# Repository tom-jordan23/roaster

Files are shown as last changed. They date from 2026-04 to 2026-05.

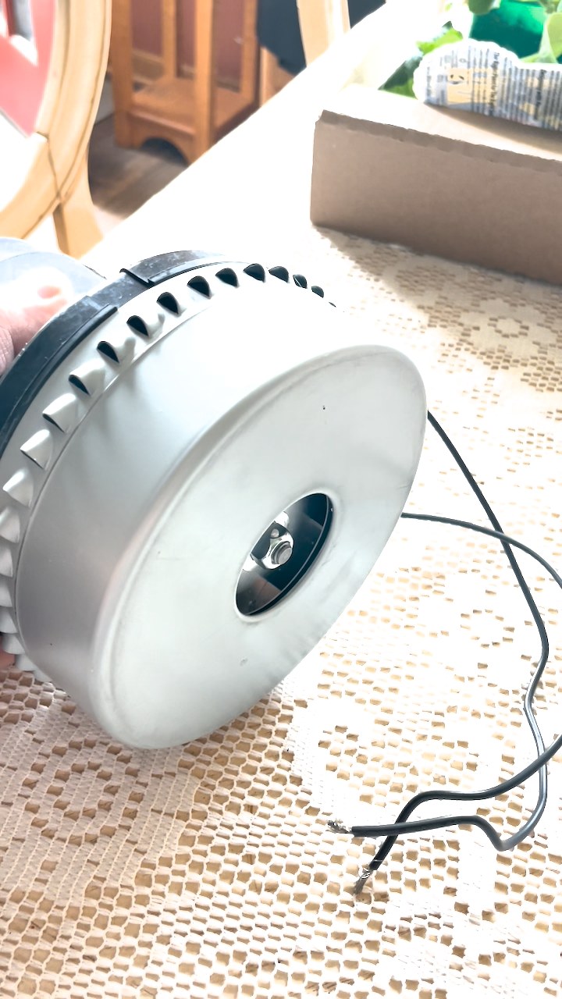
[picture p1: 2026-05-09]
build/photos/blower-motor/still_04_frame327.jpg

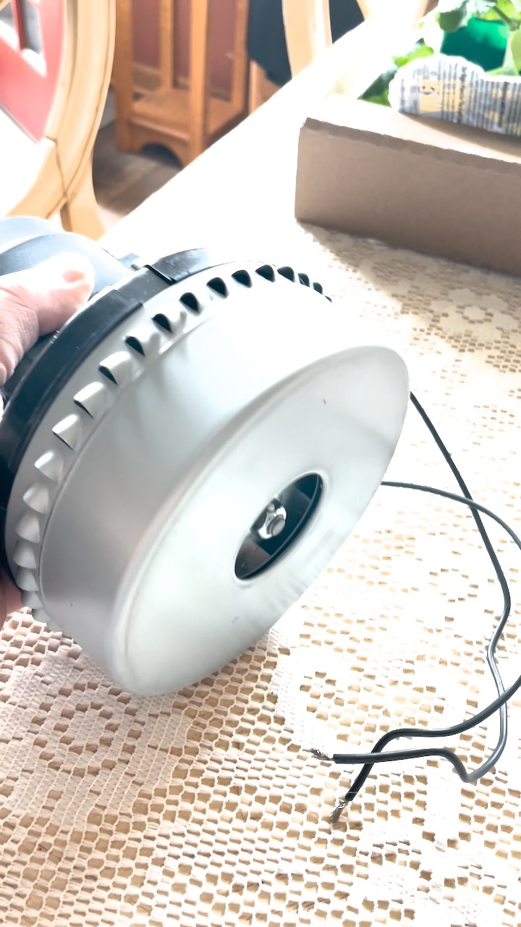
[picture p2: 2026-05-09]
build/photos/blower-motor/still_05_frame409.jpg

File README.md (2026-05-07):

# Fluid-Bed Coffee Roaster

A purpose-built small electric fluid-bed coffee roaster designed for 1/4 lb (113g) batches on 120V AC. Built as an engineering instrument and learning platform — manual operation first, closed-loop automation later.

## What This Is

A ground-up roaster design with:
- Stainless steel roast chamber with a round stovepipe plenum and side-entry heated air (DR-012)
- Distributor plate and internal baffles for uniform fluidization
- Three K-type thermocouples (process air, bean bed, exhaust)
- ESP32-based control with zero-cross SSR heater switching
- Serial command interface for manual control
- Artisan-compatible data logging
- Safety interlocks that are always authoritative

This is **not** a popcorn popper mod. It's a purpose-built fluid-bed architecture designed
to produce real roast data and evolve into a closed-loop system — built on the cheap
using thrift store finds, salvaged parts, and Amazon generics wherever possible.

## Project Status

**Phase 1 — Subsystem build (parts in hand).** Repository structure, system
architecture, power/airflow budgets, firmware scaffold, and full-design-review
disposition (DR-010) all complete. As of 2026-05-07, all major parts are in
hand: Warrior heat gun (HTR-001) torn down with element measured 1.5"×6";
salvaged bypass-cooled vacuum motor (BLW-001) measured 6"×6" cylindrical;
DR-011 control kit (TRIAC dimmer, ZMCT103C CT, line filter, ferrites);
8" stovepipe plenum body + caps (DR-012); 12"×24" steel sheet cut to
12"×18" deck with the remainder feeding the angle-iron frame extensions
(DR-013 tripod legs). Next: heater-can fabrication, plenum cure-burn,
frame extension build, electronics tray assembly, then TP-001 commissioning.

## Repository Structure

```
docs/
  system/          System block diagrams, architecture, design reviews
  mechanical/      Chamber, plenum, distributor plate, exhaust design
  electrical/      Schematics, power distribution, interlocks
  software/        Firmware architecture, Artisan integration, safety logic

firmware/          ESP32 PlatformIO project
  src/             Safety, sensors, heater, blower, control, logging, command
  test/            Unit tests (Unity framework)

bom/               Bill of materials and sourcing notes
test/plans/        Test plans TP-001 through TP-006
build/             Build instructions and progress photos
```

## Architecture Overview

### Air Path
```
Ambient → Blower → Heater Can → Plenum (side-entry) → Baffles → Distributor Plate → Chamber → Exhaust
```

### Control Stack
```
ESP32 ← 3x MAX31855 (TC1, TC2, TC3)
ESP32 → Zero-cross SSR (heater duty cycle)
ESP32 → Blower driver (speed control)
ESP32 → Serial/USB → Host PC (Artisan logging)
```

### Software Layers
1. **Safety layer** — always authoritative; over-temp shutdown, TC fault detection, airflow loss protection
2. **Manual control layer** — operator sets heater % and blower % via serial commands
3. **Automation layer** — initially stubbed; future PID on process air temp

## Firmware Commands

```
HEAT <0-100>    Set heater duty cycle %
BLOW <0-100>    Set blower speed %
STATUS          Request current state
RESET           Clear safety fault (if conditions allow)
STOP            Emergency stop — heater and blower off immediately
```

## Key Design Constraints

| Parameter | Value | Notes |
|---|---|---|
| Batch size | 113g green | 1/4 lb |
| Mains power | 120V / 15A | US residential |
| Heater budget | 1200-1500W | Salvaged from hair dryer or heat gun |
| Airflow (blower side) | 6-15 CFM | Range covers both chamber sizes |
| Chamber (primary) | 2.5" OD SS tube (~60mm ID) | Better thermal efficiency |
| Chamber (backup) | 3.0" OD SS tube (~73mm ID) | Easier fluidization |
| TC sample rate | 4 Hz polling, 2 Hz output | Artisan-compatible |
| Target BOM cost | $50-80 | Thrift-first sourcing strategy |

## Test Plan

Six test plans cover the full commissioning sequence:

| Plan | Name | Scope |
|---|---|---|
| TP-001 | Airflow | Distributor plate uniformity, fluidization verification |
| TP-002 | Thermal | Heater step response, steady-state characterization |
| TP-003 | Electrical Safety | Ground continuity, isolation, strain relief, smoke test |
| TP-004 | Firmware Unit | Automated tests + manual bench verification |
| TP-005 | Integration | Full system hot test with beans (not a roast) |
| TP-006 | First Roast | Conservative first roast through first crack |

Tests execute in order. Each depends on the prior test passing.

## Development Phases

| Phase | Goal | Gate |
|---|---|---|
| 0 - Foundation | Repo, architecture, budgets, firmware scaffold | DG-0: Agree on chamber size, heater watts, airflow rate |
| 1 - Subsystem Design | Mechanical, electrical, firmware module design | DG-1: Lock interfaces between subsystems |
| 2 - Detail | Fabrication drawings, final schematic, BOM, unit tests | DG-2: BOM ordered, firmware tests pass |
| 3 - Build & Commission | Assembly, test execution, first roast | DG-3: First roast data reviewed |

## Cost Strategy

This is a v1 learning platform built to be cheap and iterable. Major cost savings:

- **Heater element** — Harbor Freight Warrior heat gun, donor only ($10, DR-002)
- **Blower** — bypass-cooled vacuum motor salvaged from a junk shop vac
  ($0-10, DR-011); TRIAC dimmer + ZMCT103C current sensor for control
- **Chamber** — standard SS exhaust pipe from auto parts store ($8-12 each)
- **Plenum** — 8" round black stovepipe + pipe caps ($0 from scrap; ~$6 retail) (DR-012)
- **Electronics** — Amazon generic ESP32, MAX31855, SSR, TCs ($35-50 total)
- **5V supply** — old phone charger from junk drawer ($0)

We design the mechanical assembly around whatever parts we find, not the other way
around. See [`docs/system/design-reviews/DR-001-cost-strategy.md`](docs/system/design-reviews/DR-001-cost-strategy.md)
for full rationale.

## Design Documents

- [`claude.md`](claude.md) — full design rationale and decision history
- [`docs/system/design-log.md`](docs/system/design-log.md) — running design log
- [`docs/system/design-reviews/`](docs/system/design-reviews/) — formal decision records

## Building the Firmware

Requires [PlatformIO](https://platformio.org/).

```bash
cd firmware
pio run          # Compile
pio test         # Run unit tests
pio run -t upload  # Flash to ESP32
```

## License

This is a personal engineering project. No license specified yet.

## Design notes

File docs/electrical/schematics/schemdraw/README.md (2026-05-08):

# SchemDraw schematics

Source-of-truth schematics for the roaster, generated from Python via
[SchemDraw](https://schemdraw.readthedocs.io/). SVGs are checked in;
PNGs are regenerated alongside.

## Diagrams

| Source | Output | Domain |
|---|---|---|
| `01_mains_entry.py` | `out/01_mains_entry.svg` | Mains entry, DPST disconnect, fuse |
| `02_heater_circuit.py`  | `out/02_heater_circuit.svg` | Domain 1 - SSR, heater, thermal fuses, snubber, NPN buffer |
| `03_blower_circuit.py`  | `out/03_blower_circuit.svg` | Domain 2 - TRIAC dimmer, vacuum motor, CT, line filter, BOND-001 (DR-011) |
| `04_control_circuit.py` | `out/04_control_circuit.svg` | Domain 3 - ESP32 + 3x MAX31855 SPI bus + cross-domain stubs |
| `05_grounding.py` | `out/05_grounding.svg` | Star grounding plan (chassis vs. signal) |
| `06_panel_mains_entry.py` | `out/06_panel_mains_entry.svg` | Panel-wiring zone 1/4: mains entry (cord, switch, fuse, buses) |
| `07_panel_heater_bay.py`  | `out/07_panel_heater_bay.svg` | Panel-wiring zone 2/4: heater bay (thermal fuses, SSR, drive buffer) |
| `08_panel_blower_bay.py`  | `out/08_panel_blower_bay.svg` | Panel-wiring zone 3/4: blower bay (filter, CT, dimmer, motor) |
| `09_panel_control_bay.py` | `out/09_panel_control_bay.svg` | Panel-wiring zone 4/4: control bay (PSU, ESP32, MAX31855 ×3) |

## Regenerate

```bash
./docs/electrical/schematics/schemdraw/render_all.sh
```

The script bootstraps a venv at `<repo>/.venv-diagrams/` on first run
(requires `python3` and `python3-venv`). Subsequent runs reuse it.

## Conventions

- **Wire colors**: red = mains hot (L), grey = mains neutral (N),
  green = protective earth (PE), orange = +5 V logic supply,
  purple = 3.3 V logic, black = signal.
- **Boxes**: drawn with the `box(d, x0, y0, x1, y1)` helper in `common.py`.
  Always pass absolute drawing coordinates - the helper handles the
  element-relative-corner and element-direction footguns.
- **Em-dashes break the SVG backend**. Use `-` in labels.

## Editing

Each script is small and self-contained. Open one of the existing files to
see the coordinate-grid pattern: declare a few `Y_*` and `X_*` constants,
then place every element with `.at((x, y))` in absolute coordinates. Avoid
relying on cursor position after the first element - schemdraw inherits
direction from the previous element, which has bitten us already.

After editing a `.py`, run `render_all.sh` (or `python <name>.py` for one).

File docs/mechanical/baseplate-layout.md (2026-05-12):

# Baseplate Layout — Mechanical and Electronics Placement

## Purpose

Top-down layout of the v1 roaster baseplate: where each major component sits,
where the electronics tray goes, and how mains and signal wiring are routed.

This doc is **manual-first text + diagrams**. The OpenSCAD model
(`roaster-assembly.scad`) does not yet reflect this layout; SCAD changes are
gated on the vacuum motor being in hand (DR-011, design-log
2026-04-29). Once the motor is measured, both the SCAD model and this doc
should be updated together.

References: `docs/system/architecture.md` §3, `docs/electrical/schematics/power-schematic.md`,
`docs/system/design-log.md` (DR-005, DR-007, DR-008, DR-009, DR-011), `bom/bom-master.csv`.

---

## 1. Constraint Audit Against the SCAD Model

Numbers below reflect the as-built **12" × 18" steel deck** cut from the
24" BASE-001 stock, mounted on a 1"-class angle-iron frame with rear and
front extensions for the motor and electronics tray respectively (the
remaining 6" of stock is reserved for the frame extension stock and
gussets). The motor (BLW-001) and heater element (HTR-001) are now in hand
and measured; previous placeholder geometries are replaced with measured
values.

| Parameter | Value | Notes |
|---|---|---|
| Deck | 305 × 457 mm (12" × 18") | Steel sheet cut from the BASE-001 24" stock; the air train sits on this, and motor/electronics live on frame extensions outboard of it |
| Frame | 1"-class angle iron: perimeter on the deck + a rear extension for the motor + a front extension for the electronics tray | M1 stiffening + structural carry for off-deck loads. Final extension lengths set by §3 below |
| Legs | 3× threaded rod tripod, extending above and below baseplate | DR-013 tip-resistance strategy: rods continue up past the baseplate to a clamp around the cone reducer or upper chamber. Tripod gives lateral stability without the complications of running the chamber tube down into the plenum (TC-002 mount, chamber swap). Below the baseplate, same rods are the feet — adjustable for leveling |
| Plenum footprint | 203 mm dia × 152 mm tall (8" × 6") | DR-012 — round black stovepipe, both ends capped; vertical axis |
| `heater_can_length` | 178 mm (7") | **Measured 2026-05-07** — 1.5" × 6" Warrior element pack + ~0.5" each end for inlet/outlet fittings; 2.5" OD SS exhaust pipe (HTR-CAN-001) |
| `blower_dia` × `blower_height` | 152 × 152 mm (6" × 6"), vertical-axis cylinder | **Measured 2026-05-07** — aftermarket Lamb 116336-01-pattern bypass-cooled vacuum motor (BLW-001) in hand; outlet exits radially at heater-can centerline elevation |

### Air-train pack length and frame extensions

Working from the design pack length along the long (Y) axis, with the
motor and plenum on extensions outboard of the deck:

    rear extension ─ deck (457 mm) ─ front extension
    ┌──── motor 152 ────┬─── heater can 178 ──┬── plenum 203 ──┐ ── electronics tray ──┐
    │ entirely on rear  │     on deck         │   on deck      │  on front extension   │
    └ extension (~152)  │ (Y=25 to Y=203)     │ (Y=228 to 431) │  (Y=470 to ~595)      ┘

- **Motor** (Zone A, rear): mounted entirely on the rear angle-iron extension,
  body centered ~75 mm rear of the deck rear edge. Outlet faces forward and
  joins the heater can at the deck rear edge via a short flex elbow + hose
  clamp. **Rear extension length: ~152 mm (6").**
- **Heater can** (Zone B): on the deck, axis along Y, occupies Y = 25 mm to
  Y = 203 mm (25 mm rear margin for the motor-outlet joint).
- **Plenum** (Zone C): on the deck, vertical axis, with the side-entry stub
  (PLEN-005) crossing Y = 203 mm to Y = 228 mm. Plenum body (8" dia) occupies
  Y = 228 mm to Y = 431 mm — sits comfortably inside the 457 mm deck with
  ~26 mm front-edge margin to the heat-barrier line.
- **Electronics tray** (Zone D): on a front angle-iron extension, ~125 mm
  (5") deep, behind the heat barrier shield. Mounting it on an extension
  (rather than cramming it into the 26 mm of deck remaining) is the cleanest
  way to preserve the original 5"-deep enclosure while keeping the deck
  reserved for the air train. **Front extension length: ~125 mm (5").**

Total assembly footprint along Y: 152 (rear ext) + 457 (deck) + 125 (front
ext) = **734 mm (28.9")**. This is comparable in length to the originally
planned 24" baseplate but with the heat-bearing portion (deck + air train)
restricted to the 18" steel sheet — the angle-iron extensions carry only
cool-zone loads (motor body which runs at 60–80°C ambient, electronics
tray which targets <40°C internal).

### Why this layout

1. **Motor off the deck.** The motor is the heaviest single part and is the
   primary tipping moment contributor. Placing it on a rear angle-iron
   extension, with the rear pair of tripod legs straddling it, anchors the
   motor weight directly to the legs rather than cantilevering it over the
   deck edge.
2. **Plenum on deck, near front-of-deck.** The plenum carries the chamber
   stack — the tallest, most tip-prone subassembly — so it stays inboard of
   the deck where the front pair of tripod legs and the chamber-band clamp
   (DR-013) provide rigid support.
3. **Heat-barrier sheet between the plenum and the electronics tray.** The
   barrier bolts to the deck front edge with grommeted pass-throughs for the
   SSR drive pair and the TC leads (see §4.1). Putting the electronics tray
   on a front extension preserves the ~1" air gap and keeps the barrier free
   of cable congestion.
4. **Steel deck reserved for the hot zones (B + C).** The deck takes the
   thermal load (heater can + plenum, both >150°C surface temps even
   insulated). Cool-zone components (motor envelope at 60–80°C, electronics
   at <40°C) sit on angle-iron extensions outboard of the deck where the
   thermal gradient is small.

---

## 2. Layout Zones

The full assembly footprint is divided into five functional zones. Zones A–D
lie along the long (Y) axis on the baseplate plane; Zone E rises vertically
above the front extension. Zones B and C live on the 12" × 18" steel deck;
Zones A and D live on angle-iron frame extensions outboard of the deck;
Zone E is a vertical riser carrying the Pi 5 host + 7" display (DR-017):

```
       +Y (operator / front edge)
                ┌───────────────────────────────┐
                │   ZONE E — HOST UI (riser)    │ ← vertical, tilted back ~20°
                │   Pi 5 + 5×7" HDMI touch      │   facing operator
                │   mounted to a stalk          │
                └──────────┬────────────────────┘
                           │ riser attaches to front edge of
                           │ front extension; USB-A cable
                           ▼ drops back into Zone D
       ┌─ FRONT EXTENSION (~5" × 12" angle-iron tray support) ─┐
       │  ZONE D — ELECTRONICS TRAY        ~5" × 12"           │
       │                                                       │
       ╠═══════════════════ heat barrier ══════════════════════╣ ← deck front edge
       ║  ZONE C — PLENUM + CHIMNEY        ~8" dia, on deck    ║
       ║          (8" round stovepipe per DR-012;              ║
       ║           tripod legs straddle it — DR-013)           ║
       ║                                                       ║
       ║  ZONE B — HEATER CAN + SSR        ~7" × 4", on deck   ║   air-train axis
       ║                                                       ║
       ╠═══════════════════════════════════════════════════════╣ ← deck rear edge
       │  ZONE A — BLOWER + AC CONTROL     6" dia motor body   │
       │          (vertical axis) + TRIAC dimmer + line filter │
       │  [MAINS ENTRY: cord grip → DPST → fuse]               │
       └─ REAR EXTENSION (~6" × 12" angle-iron motor cradle) ──┘
       -Y (rear edge)
```

| Zone | Location | Function | Thermal class | EMI class |
|---|---|---|---|---|
| A | Rear extension (off deck) | Blower, TRIAC dimmer, line filter, mains entry, CT, ferrites | Warm (motor body 60–80°C) | **Hot** (TRIAC + brushed motor) |
| B | Deck (Y = 25–203 mm) | Heater can, SSR + heatsink, snubber, airstream thermal fuse, TC1 | **Hot** (can surface >200°C even insulated) | Quiet |
| C | Deck (Y = 228–431 mm) | Plenum, chimney, distributor plate, baffle, TC2, exhaust + chaff collector + TC3 | Hot (plenum 150–200°C, chimney 100–200°C) | Quiet |
| D | Front extension (off deck) | ESP32, MAX31855 ×3, 5V PSU, SSR drive buffer, CT bias network, USB out | **Cool** (target <40°C) | **Quiet** (target) |
| E | Riser above front extension | Pi 5 host + 5×7" HDMI touch display, USB tether down to Zone D | **Cool** (target <40°C, Pi 5 rated 0–50°C ambient) | Quiet |

The heat barrier is a vertical sheet-metal shield bolted to the deck front
edge between Zones C and D, with grommeted pass-throughs for the SSR DC
drive pair and the TC probe leads. The shield is bonded to chassis ground.
Putting Zone D on the front extension (rather than on the deck itself)
preserves the original ~1" air gap behind the barrier without crowding the
plenum.

---

## 3. Air-Train Component Placement (Zones A–C)

### 3.1 Blower (Zone A — rear extension)

| Aspect | Spec |
|---|---|
| Component | BLW-001 (aftermarket Lamb 116336-01-pattern bypass-cooled vacuum motor) — **in hand 2026-05-07** |
| Body geometry | Cylindrical, **6" dia × 6" tall** (152 × 152 mm); shaft vertical |
| Mounting position | Centered on the rear angle-iron extension, ~75 mm rear of the deck rear edge; body centerline aligned with the air-train Y axis |
| Mounting hardware | Bolted to a sheet-metal saddle or strap, sitting on the angle-iron extension. Tripod rear legs straddle the motor on either side |
| Outlet routing | BLW-HOUS-001 fan shell on top of motor; outlet is **axial** (vertical, parallel to motor shaft, off-center on the dome face). BLW-ELBOW-001 1.5in silicone 90° elbow turns the discharge horizontal-forward, then BLW-COUP-001 1.5→2.5in silicone reducer carries it across the deck rear edge to the heater can inlet at heater-can centerline elevation. (Axial-outlet shape was confirmed via product-photo inspection 2026-05-09 — DR-015) |
| Cooling exhaust | Directed away from operator and Zone D (down through a clearance gap in the rear extension, or sideways out −X) |
| Vibration isolation | Rubber feet or grommeted bolts at the saddle/extension interface; the universal motor will vibrate |
| Frame bonding | BOND-001 — ring terminal under a frame screw to the chassis-ground bus |

### 3.2 AC blower control (Zone A, adjacent to motor)

| Aspect | Spec |
|---|---|
| BLW-CTRL-001 | TRIAC dimmer module on standoffs ~50 mm from motor body |
| FILT-001 | AC line filter, inline on motor L+N leads, between fuse bus and dimmer |
| CT-001 | Split-core CT clamped on the motor's L lead **between the dimmer and the motor** so it sees the gated AC waveform |
| FERR-001 | Snap-on ferrite on motor leads between the dimmer output and the motor body |

The TRIAC dimmer must stay near the motor — short motor leads bound the
EMI source. Only three logic-level wires (PWM, ZC, GND) leave Zone A
toward Zone D.

### 3.3 Heater can (Zone B)

| Aspect | Spec |
|---|---|
| Component | HTR-CAN-001 (built per M5: 2.5" SS exhaust pipe, element on mica former, ceramic fiber wrap exterior) |
| Element | HTR-001 Warrior 1500W nichrome on mica former, **measured 2026-05-07: 1.5" wide × 6" long element pack** |
| Can length | **178 mm (7")** — 6" element + ~0.5" each end for inlet/outlet transition fittings |
| Can OD | 2.5" (~64 mm) SS exhaust pipe |
| Mounting | Cradled in two formed sheet-metal saddles bolted to deck; saddles lined with high-temp gasket to avoid metal-to-metal heat conduction |
| Joints | Hose clamp at blower outlet (preserves DR-005 bypass-cooling option); hose clamp at plenum side-entry stub tube (PLEN-005, M2) |
| THFUSE-001 | Mounted on can body exterior, in series with heater (independent of MCU) |
| THFUSE-002 | Mounted in the heated airstream, downstream of the element, immediately upstream of the plenum side-entry (E6) |
| TC1 | K-type probe via TC-FIT-001 compression fitting, in the heated airstream just upstream of plenum side-entry |

### 3.4 SSR (Zone B, baseplate-side of the heat barrier)

| Aspect | Spec |
|---|---|
| Component | SSR-001 + finned heatsink |
| Position | On the +Y side of the heater can, between can and the heat barrier |
| Heatsink orientation | Fins vertical for natural convection (~15–20 W dissipation at 12.5 A continuous) |
| Snubber | R-SNB + C-SNB across SSR output terminals (E10) |
| DC drive | Two short pigtails (SSR+, SSR-) cross the heat barrier through a grommet to Q2 buffer in Zone D |

The SSR is *not* in the electronics tray. Keeping it on the air-train side
shortens the high-current SSR-to-element wiring and concentrates the
Zone D enclosure on cool-running parts only.

### 3.5 Plenum and chimney (Zone C)

The plenum (DR-012: 8" dia × 6" tall black-stovepipe section, both ends
pipe-capped) sits centered on the +Y portion of the baseplate, vertical
axis. The chimney (distributor plate → roast chamber → cone reducer →
chaff expansion chamber → mesh screen) rises from the top cap, which is
drilled to the chamber OD and carries the clamping ring on its underside.
This zone is driven by DR-008, DR-009, DR-012 and is unchanged by DR-011.

Round footprint vs. the prior rectangular steam-pan plan: the 8" diameter
exceeds the 6"×7" rectangular Zone-C estimate by ~1" on the X axis but
remains comfortably inside the 12" baseplate width once the +X wire lanes
(§5) are accounted for.

| TC | Mount point |
|----|---|
| TC-002 | Lower chamber side wall via TC-FIT-001 (bean-bed temperature) |
| TC-003 | Exhaust stream above the chamber, via TC-FIT-001 (M9) |

### 3.6 Mains entry (rear edge of Zone A)

Cord enters the rear edge through a strain relief (STRAIN-001) and runs
**along the rear edge** to:

    cord → STRAIN-001 → SW-001 (DPST) → FUSE-001 (15A) → L bus + N bus + chassis-ground bus

SW-001 is mounted through the rear face of an enclosed Zone-A panel so it
is reachable but not bumpable. (See §6 for the case where SW-001 moves to
the front face instead.)

---

## 4. Electronics Tray (Zone D)

A small enclosed or fenced area at the operator end of the baseplate,
~5" deep × 12" wide, separated from Zone C by the heat barrier.

### 4.1 Enclosure

A vented project box (~6" × 4" × 2", or fabricated from sheet metal) bolted
to the baseplate. Vents on the +Y face only (away from the heat barrier).
Target internal temperature <40°C during a roast — verify in TP-001 with a
TC taped to the inside of the enclosure.

### 4.2 Internal placement

From rear (heat-barrier side) to front (operator side):

| Row | Component | Notes |
|-----|---|---|
| Rear  | Q2 + R3 (SSR drive buffer, E7) | On the same protoboard as the ESP32; pigtails through the heat-barrier grommet to SSR DC input |
| Rear  | CT bias network (burden R + offset divider) | Short shielded run from CT-001 in Zone A; bias network references signal ground |
| Mid | ESP-001 (ESP32-DevKitC) | On standoffs; orientation chosen so USB connector faces the front face of the enclosure |
| Mid | TC-AMP-001 ×3 (MAX31855 boards) | Same protoboard as ESP; CS lines short (<50 mm) |
| Front | PSU-001 (5V USB charger) | Mains side of the enclosure; output USB-A or pigtailed to ESP32 VIN |
| Front face | USB-B / USB-C pass-through | Strain-relieved, to host PC running Artisan |
| Front face | Optional indicator LEDs or small status display | Future — not v1 |

### 4.3 Components that do **not** live in the electronics tray

| Component | Lives in | Why |
|---|---|-----|
| BLW-CTRL-001 (TRIAC dimmer) | Zone A | Keep motor leads short; bound the EMI source |
| CT-001 | Zone A | Must be physically clamped on a motor lead |
| FILT-001 | Zone A | Inline on motor mains leads |
| FERR-001 (motor-side) | Zone A | On motor leads |
| FERR-001 (TC-side) | One on each TC SPI cable, both at the amp end and the probe end | Distributed; not localized |
| SSR-001 + heatsink | Zone B | Air-train side of heat barrier; short high-current wiring to element |
| THFUSE-001 / THFUSE-002 | Zone B | On the can body and in the airstream |
| FUSE-001 + SW-001 | Rear edge of Zone A (or front face — see §6) | Mains protection lives with mains entry |

---

## 5. Host UI Mount (Zone E)

Zone E carries the **Pi 5 + 5×7" HDMI touch display** (DR-017) as an
integrated unit mounted to the front edge of the front extension, rising
vertically above Zone D. The display faces the operator; the Pi mounts
behind the display so the whole assembly is a single tilt-back stalk.

### 5.1 Geometry

| Aspect | Value | Notes |
|---|---|---|
| Display active area | ~127 × 178 mm (5" × 7") | On hand — generic HDMI panel |
| Display + bezel (estimated) | ~152 × 203 mm (6" × 8") | Verify on the actual display before final bracket fab (G3) |
| Pi 5 PCB | 85 × 56 mm | Mounted directly to the back of the display via M2.5 standoffs |
| Riser base footprint | ~75 × 100 mm | Bolts to the front face of the front extension; small footprint so it doesn't crowd Zone D |
| Display orientation | Landscape, tilted back ~15–20° | Comfortable operator viewing angle while standing |
| Pi 5 cooling clearance | ≥20 mm above the active cooler fan intake | Don't enclose the back; let it breathe |

### 5.2 Mount detail

The riser is fabricated from BASE-001 angle-iron offcut or 1"-class steel
flatbar. Two M5 bolts through the front extension face into a vertical
stalk; stalk top carries a flat plate to which the display is fastened
through its existing VESA-style or perimeter mount holes. Pi 5 mounts to
standoffs on the back of the display plate.

### 5.3 Cable routing

Two cables run from Zone E down into Zone D:

- **micro-HDMI → HDMI** (`UI-005`): video from Pi 5 to display. Both cable
  ends stay in Zone E; the cable does not cross zones.
- **USB-A → display USB** (combined power + touch): runs along the back of
  the riser, ferrite at the Pi end, terminates at the display's USB port.

A third cable runs from Pi 5 USB-A out to the ESP32 in Zone D:

- **USB-A → ESP32** (`UI-006`): drops vertically from the Pi 5 down the
  back of the riser, ferrite at the Pi end, follows the +X signal lane
  into Zone D's front face USB pass-through.

All three cables travel along the back of the riser, out of operator sight.

### 5.4 Thermal considerations

Pi 5 is rated 0–50°C ambient. The riser places the Pi ~250 mm forward of
Zone C (plenum, 150–200°C surface). The existing Zone C/D heat barrier
(see §2) plus the ~150 mm vertical separation from the deck plane keep Pi
ambient well under spec under normal operation. Verify in TP-001 with a TC
taped to the Pi 5 active-cooler intake during a soak run.

Display backlight self-heating is the secondary concern — most 5×7" panels
run cool, but enclosed mounts can trap heat behind the panel. Leave the
back of the display open (Pi 5 mounted on standoffs, not flush) for
convective dissipation.

### 5.5 EMI

The Pi 5 USB rail is the EMI-sensitive path here (the ESP32 USB serial
link rides it). Ferrites at the Pi end of the USB-to-ESP32 cable
(`FERR-001` inventory) mitigate TRIAC/motor noise re-injected via the USB
cable. WiFi (for the WebLCDs iPad bridge) lives on the Pi's internal radio
— no antenna routing needed.

### 5.6 Power

Pi 5 USB-C PSU (`UI-002`, 27 W) connects to the Pi at the riser. The
display draws its power from one of Pi 5's USB-A ports (G2 — requires
`usb_max_current_enable=1` on the Pi). No separate display PSU. The Pi's
USB-C input cord exits the back of the riser and joins the +X signal lane
back to the rear edge where it leaves the chassis alongside the mains
cord (different cord, different strain relief).

### 5.7 Open items

| Item | What unblocks it |
|---|---|
| Exact display dimensions + mount-hole pattern | Pull the display, measure perimeter, identify any factory mount holes |
| Riser stalk height | Set so display centerline is at operator eye level when standing in front of the assembly (~1100–1300 mm above floor); needs the leg height from DR-013 to pin down |
| Cardboard mockup of Zone E + Zone D fit | Cut a 152 × 203 mm cardboard rectangle, position on the riser stub, verify it doesn't shadow the air-train work area or block the chamber view |

---

## 6. Wire Routing — Three Lanes

All wiring runs along the **+X edge** of the baseplate (the long edge
opposite the air train), in three physically separated channels. This
keeps wiring entirely outside Zones B and C's hot/EMI footprint.

| Lane | Position | Carries | Wire spec |
|---|---|---|---|
| **Mains** | Elevated raceway ~25 mm above baseplate, on the +X edge | L/N from cord through fuse and switch; L+N to SSR; L+N through FILT-001 and TRIAC to motor | 14 AWG THHN, in metal conduit or solid raceway |
| **Heater control** | Short crossing of the heat barrier through a grommet, **perpendicular** to the mains lane | SSR DC input pair (5V, GND from Q2 buffer) | 22 AWG twisted pair |
| **Signal** | Plastic raceway ~25 mm **below** the mains lane, on the **outside** of the +X edge | TC SPI runs to TC1/TC2/TC3 amps (already inside the tray, so most of this lane is the TC probe leads going *up* the chimney); CT-001 secondary leads from Zone A to the bias network in Zone D; ESP32-to-dimmer logic (PWM, ZC, GND) | 22 AWG silicone hookup; shielded cable for SPI runs and CT secondary; twisted pair for ZC and PWM |

### Routing rules

- **No shared conduit** between mains and signal lanes — separate raceways.
- **Right-angle crossings only** when the signal lane must cross the
  mains lane; minimize crossing length.
- **Ferrite at every crossing** (FERR-001 inventory).
- **Ferrite at both ends of every TC SPI cable** (E13 + DR-011 EMI plan).
- **Shield grounded at one end only** (the ESP32 / amp end) to prevent
  ground loops.
- **CT-001 secondary** is a twisted shielded pair from Zone A to the bias
  network in Zone D; the secondary is referenced to signal ground via the
  bias network — **not** to chassis ground.

### Grounding bus

A single chassis-ground bus (brass strip or grounding stud) on the
**rear-right corner** of the baseplate, fed from the green wire of the
mains cord. Star topology — no daisy-chains. Bond points, each on its own
dedicated wire to the bus:

- Plenum pan ground lug
- Heater-can ground lug
- SSR heatsink (if metal)
- Blower motor frame (BOND-001)
- Heat-barrier shield
- Baseplate (if metal)

Signal ground (5V PSU GND, ESP32 GND, MAX31855 GNDs, TRIAC dimmer logic
GND) returns to a star point at the 5V PSU output, **not** to chassis
ground. Reaffirms the existing rule from `power-schematic.md`.

---

## 7. Open Issues / Pending Parts

| Item | Why it's pending | What unblocks it |
|---|---|---|
| ~~Motor footprint and outlet geometry~~ | ~~DR-011: salvaged motor not yet on bench~~ | **In hand 2026-05-07** — 152 × 152 mm vertical-axis cylinder; outlet geometry confirmed sufficient for vertical-axis mount |
| ~~Heater-can length~~ | ~~HTR-001 not yet torn down~~ | **Measured 2026-05-07** — element 1.5" × 6"; HTR-CAN-001 length set to 178 mm (7") |
| ~~Plenum body sourcing~~ | ~~PLEN-001 thrift hunt pending~~ | **Resolved by DR-012** — black stovepipe scrap on hand; 8" × 6" target |
| ~~Baseplate sheet sourcing~~ | ~~BASE-001 not yet sourced~~ | **Sourced 2026-05-02; cut to 12" × 18" deck 2026-05-07** — angle iron from same stock for perimeter + rear (motor) and front (electronics) extensions |
| Frame extension fabrication | Rear extension (~6") and front extension (~5") not yet built | Cut and weld/bolt angle iron onto the deck perimeter; install motor saddle on rear extension; install electronics-tray cradle on front extension |
| Electronics enclosure dimensions | SSR heatsink size and PSU brick size both still nominal | Parts received (most are now in hand 2026-05-07; lay them out and finalize the project box dims) |
| SW-001 placement (rear vs front face) | Reachability vs. cable-length tradeoff | Decide once Zone-A panel orientation is fixed by motor geometry |
| Verification of <40°C inside Zone D | Depends on heat-barrier effectiveness | TP-001 — instrument enclosure interior with a TC during a soak run |
| ~~L-bracket / ballast plan for stability (M1)~~ | ~~Depends on final mass distribution~~ | **Resolved by DR-013** — threaded-rod tripod legs continuing up to a chamber clamp provide lateral tip resistance. Final rod length and clamp height set once chamber stack is assembled |
| Tripod foot positions | Depends on final extension geometry | Front pair straddle the plenum on the deck; rear pair straddle the motor on the rear extension. Final coordinates set once the angle iron is cut |
| Zone E riser geometry (DR-017 G3) | Display perimeter dimensions and mount-hole pattern not yet measured; riser stalk height depends on final leg length | Pull the on-hand 5×7" display, measure perimeter, identify any factory mount holes; cardboard-mock the assembly against the air-train view before drilling |

---

## 8. Cross-References

- Architecture: `docs/system/architecture.md` §3, §3.1, §8
- Schematics: `docs/electrical/schematics/power-schematic.md`
- BOM line items used in this doc: HTR-001, HTR-CAN-001, BLW-001,
  BLW-CTRL-001, CT-001, FILT-001, FERR-001, BOND-001, SSR-001, ESP-001,
  TC-AMP-001 (×3), TC-001/002/003, TC-FIT-001, PSU-001, SW-001, SW-002,
  LED-001, LED-002, FUSE-001, STRAIN-001, THFUSE-001, THFUSE-002,
  R-SNB-001, C-SNB-001, Q2-001, R3-001, PLEN-001, PLEN-005, BASE-001,
  UI-001 through UI-007
- Design decisions referenced: DR-002, DR-005, DR-007, DR-008, DR-009,
  DR-011, DR-016, DR-017; M1, M2, M5, M9; E6, E7, E10, E13; T1
- SCAD model (to be updated when motor is in hand): `docs/mechanical/drawings/roaster-assembly.scad`

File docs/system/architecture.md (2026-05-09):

# System Architecture and Power/Airflow Budget

## Purpose

This document captures the foundational engineering calculations that constrain
component selection across all disciplines. The three critical numbers —
**heater wattage**, **airflow rate**, and **blower static pressure** — must be
established before detailed subsystem design can proceed.

These are first-pass estimates for a 1/4 lb (113g) green coffee batch on 120V AC.

---

## 1. Heater Power Budget

### Approach

Estimate the power needed to heat a stream of air from ambient to roast-process
temperature at the required airflow rate.

### Knowns and Assumptions

| Parameter | Value | Source |
|---|---|---|
| Batch size | 113 g green coffee | Design decision |
| Target process air temp (TC1) | 200–250°C | Typical fluid-bed roast range |
| Ambient air temp | 20°C | Assumed room temp |
| Required ΔT | 180–230°C | Process air minus ambient |
| Available mains | 120V / 15A circuit | US residential standard |
| Max continuous draw | ~1440W at 12A | Leave headroom on 15A breaker |

### Thermal Calculation

Power to heat air:

    P = ṁ × Cp × ΔT

Where:
- ṁ = mass flow rate of air (kg/s)
- Cp = specific heat of air ≈ 1005 J/(kg·°C)
- ΔT = temperature rise (°C)

For a target airflow of ~35 CFM (see Section 2 below):

    35 CFM ≈ 0.0165 m³/s
    ρ_air at 20°C ≈ 1.2 kg/m³
    ṁ ≈ 0.0165 × 1.2 = 0.0198 kg/s

Power for ΔT = 200°C:

    P = 0.0198 × 1005 × 200 ≈ 3980 W

Power for ΔT = 180°C:

    P = 0.0198 × 1005 × 180 ≈ 3580 W

### Problem: 120V Constraint

At 120V / 15A, we have at most ~1500W available (with blower and controls overhead,
realistically ~1200-1400W for the heater).

This means we **cannot** heat 35 CFM of air to 250°C. We must either:

1. **Reduce airflow** — use the minimum airflow needed for fluidization
2. **Accept lower process air temps** — rely on longer roast times
3. **Both** — minimize airflow, accept moderate temps, and tune from there

### Revised Estimate: Minimum Viable Airflow

For 113g of green coffee in a ~3" diameter chamber, fluidization likely requires
significantly less than 35 CFM. Estimates from similar small roasters suggest
**15-25 CFM** may be sufficient (see Section 2).

At 20 CFM:

    20 CFM ≈ 0.00944 m³/s
    ṁ ≈ 0.00944 × 1.2 = 0.01133 kg/s

Power for ΔT = 200°C:

    P = 0.01133 × 1005 × 200 ≈ 2277 W

Still too high. At ΔT = 120°C (process air at 140°C — low but possibly workable
with extended roast and recirculated heat from the bean mass):

    P = 0.01133 × 1005 × 120 ≈ 1365 W  ✓ Fits 120V budget

### Working Heater Specification

| Parameter | Target | Notes |
|---|---|---|
| Heater power | **1200–1400W** | Constrained by 120V/15A |
| Heater element type | Nichrome on mica former (Warrior heat gun) | Salvaged from HF SKU 56434 |
| Heater voltage | 120V AC | Switched by zero-cross SSR |
| Expected process air ΔT | 100–150°C at working airflow | Actual achievable temp depends on airflow, losses |

### Implications

- The 120V constraint makes this a **thermally modest** system
- Roast times will likely be **longer than commercial fluid-bed roasters** (8-15 min vs 5-8 min)
- Insulating the heater can and plenum will matter for efficiency
- The distributor plate and chamber should minimize heat loss
- **This is acceptable for v1** — the goal is to characterize and learn, not to match commercial speed

---

## 2. Airflow Budget

### Fluidization Requirements

For green coffee beans (~7mm equivalent diameter, ~1.1-1.3 g/cm³ density):

**Minimum fluidization velocity (Umf)** for coffee beans is approximately
**0.8–1.2 m/s** based on published fluidization studies and small-roaster
experience.

**T5 — Operating margin:** The original 1.5× Umf target is thin. Target
**1.8–2.5× Umf** for stable fluidization with margin for bed weight changes.
All velocity calculations must use hot-air density at process temperature
(~0.7–0.8 kg/m³ at 150–200°C), not ambient density. Previous calculations
applied this correction inconsistently.

### Chamber Cross-Section — Two Candidates

We are sourcing **two standard stainless steel tube sizes** and will test both.
This avoids committing to a chamber diameter before we have fluidization data.

**2.5" OD tubing** (ID ~2.37" / 60mm) — the thermal-efficiency candidate:

    Area = π × (0.030)² = 0.00283 m²

    Volumetric flow at 2.0× Umf = 2.0 m/s (T5: revised from 1.5×):
    Q = 2.0 × 0.00283 = 0.00566 m³/s ≈ 12.0 CFM

    Bed depth for 113g (bulk density ~0.65 g/cm³):
    V_bed = 113 / 0.65 = 174 cm³
    Depth = 174 / 28.3 ≈ 6.1 cm

    T3: L/D ratio = 6.1 / 6.0 ≈ 1.0 — WARNING: Geldart D particles (coffee beans)
    slug at L/D > 0.5-0.8. The 2.5" chamber has a significant slugging risk.

    Power for ΔT = 200°C at 12 CFM:
    ṁ = 0.00566 × 1.2 = 0.00679 kg/s
    P = 0.00679 × 1005 × 200 ≈ 1364 W  ✓ Within 120V budget

**3.0" OD tubing** (ID ~2.87" / 73mm) — the safe-fluidization candidate:

    Area = π × (0.0365)² = 0.00419 m²

    Volumetric flow at 2.0× Umf = 2.0 m/s (T5: revised from 1.5×):
    Q = 2.0 × 0.00419 = 0.00838 m³/s ≈ 17.7 CFM

    Bed depth for 113g:
    Depth = 174 / 41.9 ≈ 4.2 cm

    T3: L/D ratio = 4.2 / 7.3 ≈ 0.57 — within acceptable range for fluidization.

    Power for ΔT = 200°C at 17.7 CFM:
    ṁ = 0.00838 × 1.2 = 0.01006 kg/s
    P = 0.01006 × 1005 × 200 ≈ 2022 W  ⚠ Exceeds 120V budget

    T4: After 100-230W parasitic losses (heater can, plenum, duct walls), achievable
    process air ΔT drops to ~160-175°C. Insulating heater can and plenum is mandatory
    for the 3.0" chamber to reach usable roast temperatures.

### Comparison

| Parameter | 2.5" OD (60mm ID) | 3.0" OD (73mm ID) |
|---|---|---|
| Tube stock | Standard, cheap | Standard, cheap |
| Bed depth (113g) | ~6.1 cm | ~4.2 cm |
| L/D ratio | ~1.0 ⚠ slugging risk (T3) | ~0.57 ✓ safe range |
| CFM at 2.0× Umf (T5) | ~12 CFM | ~18 CFM |
| Watts for ΔT=200°C | ~1364W | ~2022W |
| Thermal headroom on 120V | Good | Exceeded — needs insulation (T4) |
| Fluidization risk | Deeper bed — harder, slugging | Shallower — easier |

**Decision:** Test both. The 2.5" gives us significantly better thermal performance
if it fluidizes well. The 3.0" is the safe fallback. TP-001 will determine the winner.

The plenum and distributor plate mounting interface should accommodate both tube sizes
(e.g., adapter ring or two plate sizes).

### Temperature Correction

Hot air is less dense. At process temperature (~150-200°C), air density drops to
~0.7-0.8 kg/m³. The volumetric flow rate at the distributor plate is **higher**
than at the blower inlet for the same mass flow.

This actually helps: the blower pushes cool air at lower volume, and the heated
air expands to provide higher velocity at the plate.

Blower-side CFM needed (at ambient, corrected for hot-air density T5):

    2.5" chamber: ~8-12 CFM at blower → ~12-17 CFM at plate (hot)
    3.0" chamber: ~12-18 CFM at blower → ~18-25 CFM at plate (hot)

### Working Airflow Specification

| Parameter | Target | Notes |
|---|---|---|
| Blower output (cold) | **8–18 CFM** | Must cover both chamber sizes at 2.0× Umf (T5 revised) |
| Velocity at plate (hot) | **1.6–2.5 m/s** | T5: 1.8-2.5× Umf target for stable fluidization |
| Chamber options | **2.5" OD (~60mm ID)** and **3.0" OD (~73mm ID)** | Test both, standard SS tube stock |
| Adjustable range | **30–100% of max** | Need to tune fluidization quality per chamber |

---

## 3. Blower Static Pressure Budget

### Pressure Drops Through the System

| Component | Estimated Pressure Drop | Notes |
|---|---|---|
| Heater can | 0.1–0.3" WC | Open duct with element obstruction |
| Plenum entry + baffles | 0.1–0.3" WC | Side-entry turning loss + baffle resistance |
| Distributor plate | 0.3–0.8" WC | Depends on open area ratio (target 5-15%) |
| Bean bed | 0.2–0.8" WC | Depends on bed depth and bean size (deeper in 2.5" chamber) |
| Exhaust path | 0.1–0.2" WC | Screen + ducting |
| **Total system** | **0.8–2.1" WC** | |

### Working Blower Specification

| Parameter | Target | Notes |
|---|---|---|
| Static pressure | **1.5–2.5" WC** at operating CFM | System minimum; vacuum motor has 20–80× headroom |
| Flow rate | **8–18 CFM** at operating pressure | T5: revised to cover 2.0× Umf for both chambers |
| Control | TRIAC phase/burst control from ESP32 | Universal AC motor — see §3.1 |
| Noise | Loud (vacuum-motor class) — accepted for v1 | Mitigation deferred (foam-lined enclosure post-TP-001) |

### Blower Selection (DR-011 — supersedes DR-003)

**Selected:** Aftermarket Lamb 116336-01-pattern universal-AC **bypass-cooled**
two-stage vacuum motor (Amazon B0F89ZQ23G, ~$60–90; in hand 2026-05-09).
Architecture confirmed via the Ametek Lamb Product Bulletin 116336-01 (March
1998) the part replicates and visual verification of the unit; vent map is
in `bom/bom-master.csv` BLW-001 notes and `build/photos/blower-motor/`.
Speed-controlled via a TRIAC dimmer module (RobotDyn-class AC light dimmer /
8A / built-in zero-cross detector) driven by ESP32 PWM and zero-cross
interrupt. Airflow interlock via a ZMCT103C split-core current transformer
clamped on one motor lead, sensed by ESP32 ADC.

**Selection criteria:** Must comfortably exceed system worst-case backpressure
(~2.1" WC) at 18 CFM with margin for chaff-mesh loading (T8) and bed-depth
variation. Vacuum motors deliver 20–80" WC of static pressure headroom — far
more than required, so the duty point sits in the flat part of the P-Q curve
where TRIAC speed control is well-behaved.

**Rationale:** The 120 mm × 32 mm 12 V DC centrifugal blower previously selected
(DR-003, BLW-001 / Wathai B08P1S5DBN) shut off around ~1.0–1.5" WC. At the
~12–18 CFM operating point its delivered static pressure was ~0.3–0.6" WC —
below the system minimum, with no margin for distributor-plate / chaff-mesh
loading or bed-depth variation in the 2.5" chamber. T1 was a real blocker, not
a paper one. A 24V high-pressure blower (Delta BFB1024-class, $25–50) would
have worked but conflicted with the cost-conscious sourcing constraint
(DR-001). Aftermarket Lamb-pattern vacuum motors are widely available as
drop-in replacements for OEM central-vac and floor-scrubber positions, and
TRIAC speed control of universal motors is a well-trodden DIY pattern.

**Bypass-cooled is non-negotiable for a coffee application.** Flow-through
motors cool the brushes with the working airstream and shed brush carbon into
the air the beans see. Bypass / two-stage motors have a separate cooling
impeller and isolated working impeller — only inspect a candidate motor after
confirming the cooling path is separate from the suction path.

### T1 — RESOLVED (2026-04-29)

The original T1 risk ("12V DC blower P-Q curve unverified, may not reach
operating point") is closed by the architecture change. Verification work
shifts in nature: instead of *gating* the design on whether the existing blower
reaches spec, we now characterize the motor at TP-001 to set the
**operating duty-cycle range** (e.g., 30%–60% TRIAC conduction angle for
target CFM). The motor will exceed system requirements at 100% — the question
is where to operate it, not whether it can reach spec.

### 3.1 Blower Control Subsystem (BLW-CTRL-001)

| Element | Spec | Notes |
|---|---|---|
| TRIAC dimmer module | RobotDyn-style AC dimmer, 8A, on-board zero-cross detect | ESP32 inputs: PWM + ZC interrupt; outputs: gated AC to motor |
| Current sensor | ZMCT103C 5A split-core CT | Clamped on one motor lead; biased to mid-rail; ADC-sampled |
| EMI mitigation | Snap-on ferrite chokes on all TC SPI cables, line filter on motor leads | Brushed motor + TRIAC switching is a real EMI source — E13 shielded SPI cable is necessary but not sufficient |
| Motor bonding | Motor frame bonded to mains earth via dedicated lug | Universal motors have nontrivial leakage current — earth bond is safety-critical |

ESP32 pin assignment changes (replaces the DC-blower MOSFET drive):

| GPIO | Function | Notes |
|---|---|---|
| 23 | TRIAC PWM (gate logic input to dimmer module) | Was: MOSFET gate via R1 |
| 4 | Zero-cross interrupt input (from dimmer module ZC pin) | New |
| 34 | ADC: CT current sense (airflow interlock) | New — replaces implicit `blower_is_running()` from DC PWM duty |

Firmware impact (deferred to a separate work item — not part of this doc-update
pass):
- `blower.c`: replace LEDC PWM driver with phase-angle TRIAC driver triggered
  off the zero-cross ISR
- `safety.c`: `blower_is_running()` reads CT RMS via ADC (threshold-based)
  rather than checking PWM duty
- New fault: FAULT_CT_OPEN if the CT reads zero with TRIAC commanded on

---

## 3.5. Known Thermal Losses and Mid-Roast Effects (DR-010)

These factors are documented as known but not fatal to v1. They should be
accounted for in test plan interpretation and control tuning.

### T4 — Parasitic Heat Losses

The heater can body, plenum walls, duct connections, and distributor plate all
absorb and radiate heat. Estimated parasitic losses: **100–230W** depending on
insulation and ambient conditions.

**Action:** Insulate heater can exterior and plenum walls with fiberglass wrap.
This is especially important for the 3.0" chamber, where the thermal budget
is already tight.

### T6 — Moisture Release

Green coffee contains ~10-12% moisture by weight. During roasting, moisture
release absorbs approximately **30–40W equivalent** of energy (latent heat of
vaporization). This is unaccounted for in the basic thermal budget but is not
fatal — it slightly reduces effective process air temperature during drying
phase.

### T7 — Bean Mass Changes During Roasting

Beans lose 12–18% of their mass during roasting (moisture + CO₂ + volatiles).
This changes the bed weight and therefore the fluidization velocity requirement.
Beans become lighter as the roast progresses — fluidization gets easier, and
the operator may need to reduce blower speed mid-roast to avoid blowing beans
out of the chamber.

### T8 — Chaff Mesh Clogging

The 30×30 SS mesh screen may progressively clog with chaff oils during a roast,
increasing back-pressure. Plan for mid-roast mesh cleaning if roasts stall, or
test with coarser mesh (20×20) as a fallback.

---

## 4. Summary: Key Constraining Numbers

These are the DG-0 decision parameters. All downstream design must be
consistent with these values.

| Parameter | Working Value | Hard Constraint? |
|---|---|---|
| Batch size | 113g green | Design decision |
| Mains power | 120V / 15A | Yes (US residential) |
| Heater power | 1200–1400W | Yes (120V limited) |
| Airflow (cold, blower side) | 8–18 CFM | T5: revised for 2.0× Umf, both chambers |
| Airflow velocity at plate (hot) | 1.6–2.5 m/s | T5: 1.8-2.5× Umf, verify by test |
| Chamber ID (primary) | 2.5" OD / ~60mm ID | Better thermal performance |
| Chamber ID (backup) | 3.0" OD / ~73mm ID | Easier fluidization |
| Blower static pressure | 1.5–2.5" WC system minimum | T1 RESOLVED via DR-011 — vacuum motor has 20–80× headroom |
| Process air temp (TC1) | 140–220°C achievable | Limited by heater power vs airflow |
| TC sample rate | ≥2 Hz | Artisan compatibility |

---

## 5. Cooling Cycle (DR-005)

### Approach

Blower-only cooling: SSR off (heater 0%), blower at 100%. No bypass damper
for v1.

### Thermal Mass Estimate

| Component | Mass | Cp (J/g·°C) | Energy to cool 200→50°C |
|---|---|---|---|
| Nichrome wire | ~50-80g | 0.44 | ~3-5 kJ |
| Heater can body | ~100-200g | 0.50 | ~8-15 kJ |
| **Total** | | | **~13-23 kJ** |

At 10 CFM forced convection through a 200°C element:

    ṁ × Cp × ΔT = 0.0057 × 1005 × 180 ≈ 1030 W initially

Average extraction ~500-1000W → element cools in **15-30 seconds**. After that,
air reaching the beans is near ambient temperature.

### Bean Cooling Timeline (estimated)

113g beans at ~200°C, blower at 100% (10-15 CFM ambient air):
- 0-30s: Air still warm from element thermal lag; beans cool slowly
- 30-90s: Air is near ambient; beans cooling rapidly
- 90-140s: Beans reach <50°C target

**Total estimated cooling time: 100-140 seconds** (within industry 90-150s target)

### Mechanical Provision for Future Bypass

The blower-to-heater-can joint uses a hose clamp connection (not welded). If
TP-002 data shows residual heat is problematic, options include:
1. Physically disconnect heater can during cooling (simplest)
2. Add a two-position diverter valve at the blower outlet
3. Add a second ambient air inlet on the plenum

### Firmware: COOL Command

A `COOL` command sets heater to 0%, blower to 100%, and logs cooldown curves.
Operator notification when TC2 < 50°C.

---

## 6. Chaff Collection (DR-006)

### Chaff Characteristics

| Parameter | Value |
|---|---|
| Chaff mass per 113g batch | ~0.5-0.9g |
| Particle size | ~30-60 microns |
| Release timing | Mostly at first crack |

### Design: Expansion Chamber + Mesh Screen

A removable exhaust unit mounted atop the roast chamber:

| Parameter | Value | Notes |
|---|---|---|
| Body | ~4" OD × 5" tall SS cylinder | Step-up from chamber diameter |
| Air velocity in chamber | 2-4 ft/sec | Velocity drop causes chaff to settle |
| Screen | 30×30 SS mesh | Secondary capture at top of expansion chamber |
| Cleaning | Tap-and-empty between roasts | Removable unit |
| Backpressure impact | Negligible | Expansion reduces velocity; screen is coarse enough |

### Why Not a Cyclone

A cyclone separator provides 96-99% capture but adds significant backpressure,
which directly impairs fluidization in the roast chamber. At the 113g scale
with <1g of chaff per roast, a simple expansion chamber is sufficient and adds
near-zero flow restriction.

---

## 8. Plenum Assembly (DR-007 superseded by DR-012; DR-008, DR-009)

### Plenum Body

| Parameter | Value | Notes |
|---|---|---|
| Body | 8" dia × 6" tall black stovepipe section, both ends pipe-capped | Bare/oxide-blackened mild steel, ~26 ga, rated ~1000°F continuous |
| Orientation | Vertical, axis aligned with chamber tube above | |
| Side-entry hole | 2.5" dia bi-metal hole saw through cylindrical wall | Centerline ~2" above floor (DR-009 ramp clearance); connects to heater can via PLEN-005 stub + hose clamp |
| Top closure | Slip-fit pipe cap, drilled to chamber OD | Cap face is the substrate the clamping ring attaches to (replaces the pan flange of DR-007) |
| Bottom closure | Slip-fit pipe cap | Sealed at seam with high-temp RTV; retained with 3 sheet-metal screws or rivets through cap skirt |
| Pre-assembly | Cure burn outdoors with propane torch until smoking stops | M7 carry-over: removes rolling-oil film before any food-path roasting |
| Source | Scrap on hand | $0 (scrap) / ~$6 retail for pipe + 2 caps |

### Top Assembly (no welding)

The drilled top cap captures the chamber tube laterally; the clamping ring
on the cap underside catches the chamber from below, supports the
distributor plate, and seals the cap-to-plenum joint:

| Component | Material | Attachment | Notes |
|---|---|---|---|
| Clamping ring | 1/8" SS plate, ~1" wide annular ring; 3 tapped M4 holes on bolt circle outside cap drill | M4 machine screws from above through cap face, threaded into tapped ring | **Ring ID < chamber ID** (2.0" for 2.5" chamber pair; 2.5" for 3.0" pair) so the ring's inner face supports the plate from below. Tapped ring (no nuts inside plenum) preserves DR-008 swap without breaking DR-012 bottom-cap RTV seal. M3 fender washers under cap-side screw heads to spread clamping load |
| Gasket | Fiberglass stove-rope (PLEN-004) | Sandwiched between ring and underside of cap face | Seals against hot air leakage at the chamber interface |
| Distributor plate | Perforated SS disc, **dia = chamber ID** (2.37" or 2.87") | Rests on ring face inside the chamber bottom (Option A); gravity-held | Slip fit against chamber wall — leak path around plate edge is small vs deliberate perforations. **Plate float watch:** at startup / empty operation, ~0.5 kgf lift on a ~50 g plate may exceed gravity; verify in TP-001 |
| Chamber tube | 2.5" or 3.0" OD SS tube | Slides through cap hole (drilled to chamber OD); bottom rim rests on ring face around the plate edge | Captured laterally by cap hole; vertical retention via CHAM-RET-001 (set screws or spring clips above the cap face) |

Swapping chamber sizes requires swapping the ring + plate pair. Each pair is
sized to its chamber OD; the cap (which is also size-specific because its
hole = chamber OD) is part of the swap unit too — practically this means
having a dedicated top cap drilled per chamber size, paired with its ring +
plate.

### Deflector Ramp Baffle

| Parameter | Value | Notes |
|---|---|---|
| Material | SS sheet scrap, ~3" × 4" | Bent to ~45° in vise |
| Position | Inside plenum, opposite side-entry hole | Redirects jet downward to plenum floor |
| Attachment | 2 bolts or pop rivets through cylindrical wall | Curved wall vs flat pan wall is immaterial — ramp seats on a chord |
| Function | Jet → floor spread → uniform rise to plate | Uses full plenum volume for equalization |

**T2 — Second baffle / equalization stage:** A single deflector ramp is unlikely
to fully equalize pressure — the velocity ratio at the inlet is 5–10× the
target distributor velocity. Plan to add a second equalization feature:
- Option A: Horizontal perforated baffle ~1" below the distributor plate
- Option B: Perforated diffusion plate inside plenum between ramp and distributor

The 6" plenum height (DR-012) was sized with 1" of explicit headroom for
either option without redesign. Validate in TP-001 — if the single ramp
produces acceptable fluidization uniformity, the second baffle can be
deferred.

---

## 9. Open Questions for DG-0 Review

1. ~~**Chamber diameter:** 3" is the working assumption. Should we consider 2.5"?~~
   **RESOLVED:** Sourcing both 2.5" OD and 3.0" OD standard SS tubes. Will test both.
   Plenum interface must accommodate both diameters.
2. ~~**Heater element sourcing:** What specific elements are available in the 1200-1400W
   / 120V range that fit a reasonable heater-can geometry?~~
   **RESOLVED (DR-002):** Harbor Freight Warrior 1500W heat gun (SKU 56434, ~$10).
   Nichrome on mica former. Measure element after teardown.
3. ~~**Blower sourcing:** DC brushless vs AC centrifugal — availability and cost at
   the required operating point? Must cover 6-15 CFM range with speed control.~~
   **RESOLVED (DR-003, then superseded by DR-011 2026-04-29):** Aftermarket
   Lamb 116336-01-pattern bypass-cooled universal-AC vacuum motor; speed
   control via TRIAC dimmer module + ESP32 zero-cross interrupt; airflow
   interlock via ZMCT103C CT.
   See §3 / DR-011 for rationale on the supersede.
4. **Insulation strategy:** How much can we recover by insulating the heater can
   and plenum? Worth calculating before finalizing heater spec.
5. **Roast time expectation:** Are 10-15 minute roast times acceptable for v1?
   (Likely yes, given the learning-platform philosophy.)
6. ~~**Plenum adapter design:** How to mount both chamber sizes on the same plenum —
   adapter ring, two plate sizes, or stepped seat?~~
   **RESOLVED (DR-008):** Bolted clamping ring across pan rim. Swap ring + plate
   pair to change chamber sizes. No welding.

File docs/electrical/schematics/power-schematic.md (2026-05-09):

# Power Circuit Schematic

## Mains Entry and Protection

```mermaid
graph LR
    subgraph MAINS_ENTRY["Mains Entry"]
        L_IN["L (Hot)"] --- CORD["14 AWG\nw/ strain relief"]
        N_IN["N (Neutral)"] --- CORD
        G_IN["G (Ground)"] --- CORD
    end

    CORD --- DISC["SW-001\n120V 15A DPST\nDisconnect Switch\n(E8: switches L and N)"]
    DISC --- FUSE["FUSE-001\n15A Inline Fuse"]

    FUSE --- L_BUS["L Bus"]
    N_IN --- N_BUS["N Bus"]
    G_IN --- GND_BUS["Chassis Ground Bus"]

    style DISC fill:#ff9,stroke:#333
    style FUSE fill:#f96,stroke:#333
    style GND_BUS fill:#0f0,stroke:#333
```

## Domain 1: 120V AC Heater Circuit

```mermaid
graph TD
    L_BUS["L Bus"] --> SSR_L["SSR-001\nZero-Cross SSR\n25A / 120V AC\nInput: 3-5V DC"]
    SSR_L --> HTR_L["HTR-001\nWarrior 1500W\nNichrome Element\n~9.6 ohm"]
    HTR_L --> N_BUS["N Bus"]

    THFUSE1["THFUSE-001\n228°C Thermal Fuse\n(one-shot, on can body)"] -.-|"In series\nwith heater"| HTR_L
    THFUSE2["THFUSE-002\n192-216°C Thermal Fuse\n(one-shot, in airstream)\n(E6)"] -.-|"In series\nwith heater"| HTR_L

    SNUB_R["R-SNB\n47Ω 2W"] --- SNUB_C["C-SNB\n0.01µF 400V\nX2-rated"]
    SNUB_R -.-|"RC snubber\nacross SSR output\n(E10)"| SSR_L

    ESP_SSR["ESP32 GPIO 22\n(PIN_SSR)"] -->|"3.3V logic"| Q2_BASE["Q2 Base\nNPN Buffer\n(E7)"]
    Q2_BASE -->|"5V drive to SSR"| SSR_CTRL["SSR DC Input\n(+ and -)"]
    SSR_CTRL --> SSR_L

    style SSR_L fill:#f66,stroke:#333
    style THFUSE fill:#f96,stroke:#333
```

### Heater Circuit Notes

- SSR switches L (hot) side only — N is continuous to element
- **Two thermal fuses in series (E6):**
  - THFUSE-001 (228°C): mounted on heater can body — detects can overheat
  - THFUSE-002 (192–216°C): mounted in the heated airstream downstream of element —
    detects no-airflow overheat faster (lower thermal lag than can body)
- Thermal fuses are independent backups — if SSR fails shorted and safety firmware
  fails, the thermal fuses are the last-resort cutoff
- **SSR drive buffer (E7):** ESP32 GPIO 22 drives an NPN transistor (2N2222 or similar)
  that switches a 5V signal to the SSR DC input. Many commodity SSRs need >3.5V to
  reliably trigger — 3.3V from ESP32 is marginal. The NPN buffer provides a clean
  5V drive with negligible added cost.
- **RC snubber (E10):** 47Ω + 0.01µF/400V X2-rated capacitor across SSR output terminals.
  Suppresses voltage spikes from inductive heater element switching, protects SSR.
- Zero-cross switching for burst-fire duty cycle control (1s period, HEATER_PERIOD_MS)
- **Heater draws ~12.5A at 120V** (P = V²/R = 14400/9.6 ≈ 1500W)
- **E5 — Fusing concern:** 12.5A continuous on a 15A fuse / 15A circuit is 83% of
  rating. NEC requires ≤80% for continuous loads. Options:
  1. Use a 20A circuit (12 AWG cord) — preferred if available
  2. Limit heater duty to stay under 12A continuous average
  3. Accept that v1 bench testing will likely not run 3+ hours continuously

## Domain 2: 120V AC Blower Circuit (DR-011 — supersedes DR-003)

```mermaid
graph TD
    L_BUS["L Bus"] --> FILT_L["FILT-001\nAC Line Filter\n(X + Y caps)"]
    FILT_L --> CT["CT-001\nZMCT103C\nSplit-Core CT\n(clamped on L lead)"]
    CT --> TRIAC_L["BLW-CTRL-001\nTRIAC Dimmer Module\nRobotDyn-style 8A\nw/ Zero-Cross Detect"]
    TRIAC_L --> BLWR_L["BLW-001\nUniversal-AC\nBypass-Cooled Vacuum Motor\n(L)"]
    BLWR_L --> N_BUS["N Bus"]

    BOND["Motor Frame\n→ Mains Earth\n(BOND-001)"] -.-|"Safety bond"| BLWR_L

    ESP_PWM["ESP32 GPIO 23\n(PIN_BLOWER_PWM)"] -->|"3.3V logic\n(PWM)"| TRIAC_PWM["Dimmer PWM In"]
    TRIAC_ZC["Dimmer ZC Out"] -->|"3.3V pulse\nat each zero-cross"| ESP_ZC["ESP32 GPIO 4\n(PIN_ZC_IRQ)"]
    TRIAC_PWM --- TRIAC_L
    TRIAC_ZC --- TRIAC_L

    CT_OUT["CT secondary\n(burden + bias)"] -->|"AC riding mid-rail"| ESP_ADC["ESP32 GPIO 34\n(ADC: PIN_CT_SENSE)"]
    CT --- CT_OUT

    style TRIAC_L fill:#f96,stroke:#333
    style CT fill:#69f,stroke:#333
    style BOND fill:#0f0,stroke:#333
    style FILT_L fill:#fc9,stroke:#333
```

### Blower Circuit Notes

- **BLW-001 (aftermarket Lamb 116336-01-pattern bypass-cooled vacuum motor):** Universal AC motor, ~1–4 A
  draw at 120 V depending on size. Bypass-cooled (two-stage) is required —
  flow-through motors shed brush carbon into the bean airstream. Frame is bonded
  to mains earth via BOND-001 (universal motors have nontrivial leakage current).
- **BLW-CTRL-001 (TRIAC dimmer module):** RobotDyn-class 8 A AC dimmer with
  on-board zero-cross detector. Two logic-level pins: PWM in (gate trigger), ZC
  out (pulse at each AC zero-cross). ESP32 phase-fires the TRIAC at a delay
  set by the commanded duty.
- **CT-001 (ZMCT103C 5 A split-core CT):** Clamped on one motor lead. Secondary
  output biased to ADC mid-rail with a burden resistor + DC offset divider; ESP32
  samples the AC waveform on GPIO 34 and computes RMS for the airflow interlock.
  Replaces the implicit `blower_is_running() = (PWM > 0)` check from DR-003.
- **FILT-001 (AC line filter):** X-cap line-to-neutral, Y-caps line/neutral-to-earth.
  Suppresses TRIAC-induced conducted EMI from re-entering the mains and the rest
  of the system. Mandatory for SPI signal integrity in this topology.
- **Ferrite chokes (FERR-001):** Snap-on cores on the motor leads (between TRIAC
  and motor) and on every TC SPI cable. Brushed motor + TRIAC switching is a
  significant EMI source — E13 shielded SPI cable is necessary but not sufficient.
- **PWM frequency:** Phase-angle control synchronized to mains zero-cross — not
  high-frequency PWM. The "PWM" pin on the dimmer module is really a gate trigger
  whose timing within each half-cycle determines conduction angle.
- **Speed range:** 0%–100% conduction angle maps to 0%–100% motor speed.
  Practical operating range will be the upper portion (e.g., 30%–80% conduction
  angle) — universal motors don't run smoothly at very low conduction.
- **DR-011:** Replaces DR-003 (12V DC brushless blower with MOSFET PWM).
  Resolves T1 (P-Q gap on the previous blower).

## Domain 3: 3.3V DC Control Circuit

```mermaid
graph TD
    L_BUS["L Bus"] --> PSU5_L["PSU-001\n5V / 2A\nUSB Charger"]
    N_BUS["N Bus"] --> PSU5_N["PSU-001"]
    PSU5_L --> V5_PLUS["+5V → ESP32\nOnboard 3.3V Reg"]
    PSU5_N --> V5_GND["5V GND"]

    V5_PLUS --> ESP["ESP-001\nESP32-DevKitC\n(powered via USB\nor VIN pin)"]

    ESP --> SPI["SPI Bus\nCLK: GPIO 18\nMISO: GPIO 19"]

    SPI --> AMP1["MAX31855 #1\nCS: GPIO 5\n(TC1 Process Air)"]
    SPI --> AMP2["MAX31855 #2\nCS: GPIO 16\n(TC2 Bean Bed)"]
    SPI --> AMP3["MAX31855 #3\nCS: GPIO 17\n(TC3 Exhaust)"]

    AMP1 --- TC1["TC-001\nK-Type TC\nSS Sheath"]
    AMP2 --- TC2["TC-002\nK-Type TC\nSS Sheath"]
    AMP3 --- TC3["TC-003\nK-Type TC\nSS Sheath"]

    ESP -->|"GPIO 22"| SSR_OUT["→ SSR Gate\n(Domain 1)"]
    ESP -->|"GPIO 23\n(PWM in)"| TRIAC_OUT["→ TRIAC Dimmer PWM\n(Domain 2)"]
    ESP -->|"GPIO 4\n(ZC IRQ)"| ZC_IN["← TRIAC Dimmer ZC out\n(Domain 2)"]
    ESP -->|"GPIO 34\n(ADC)"| CT_IN["← CT-001 burden\n(Domain 2 — airflow interlock)"]
    ESP -->|"USB Serial\n115200 baud"| PC["Host PC\n(Artisan)"]

    style ESP fill:#6f6,stroke:#333
```

### Control Circuit Notes

- ESP32 powered via USB (5V) — onboard regulator provides 3.3V for MCU and GPIO
- Three MAX31855 share SPI bus (CLK, MISO) with individual CS lines
- MOSI not connected — MAX31855 is read-only
- SPI clock: default ~4 MHz (MAX31855 max is 5 MHz)
- USB serial provides both power and data connection to host PC
- **All signal wiring (22-26 AWG) must be physically routed away from mains wiring (14 AWG)**

## Grounding

```mermaid
graph TD
    MAINS_GND["Mains Earth\n(green wire)"] --> GND_BUS["Chassis Ground\nBus / Stud"]

    GND_BUS --> BASE["Metal Baseplate\n(if metal)"]
    GND_BUS --> PLEN["Plenum Pan\n(ground lug)"]
    GND_BUS --> HTR_CAN["Heater Can\n(ground lug)"]
    GND_BUS --> SSR_HS["SSR Heatsink\n(if metal)"]
    GND_BUS --> BLWR_FRAME["Blower Motor Frame\n(BOND-001 — DR-011)"]

    V5_GND["5V PSU GND"] --- SIG_GND["Signal Ground"]
    SIG_GND --- ESP_GND["ESP32 GND"]
    SIG_GND --- DIM_GND["TRIAC Dimmer\nlogic GND"]

    style GND_BUS fill:#0f0,stroke:#333
    style MAINS_GND fill:#0f0,stroke:#333
```

### Grounding Notes

- **Chassis ground (earth):** All metal enclosure parts bonded to mains earth via
  dedicated ground wire. This is safety-critical — prevents shock if a mains wire
  contacts the chassis. **DR-011: vacuum motor frame must be earth-bonded** via
  BOND-001 — universal motors have nontrivial leakage current.
- **Signal ground:** 5V PSU GND, ESP32 GND, and TRIAC dimmer logic GND share a
  common return (star ground at the 5V PSU output).
- **Do NOT connect chassis earth to signal ground** unless through the PSU's
  internal earth-ground bond (most isolated switching PSUs bond earth to output
  GND via a high-value resistor or Y-cap internally).
- **CT-001 secondary** is referenced to signal ground via its bias network —
  the primary (motor lead) is mains-isolated by the magnetic coupling of the CT.

## Complete Pin Assignment Summary

| ESP32 GPIO | Function | Connected To | Wire Gauge |
|---|---|---|---|
| 18 | SPI CLK | MAX31855 x3 CLK | 22-26 AWG |
| 19 | SPI MISO | MAX31855 x3 DO | 22-26 AWG |
| 5 | TC1 CS | MAX31855 #1 CS | 22-26 AWG |
| 16 | TC2 CS | MAX31855 #2 CS | 22-26 AWG |
| 17 | TC3 CS | MAX31855 #3 CS | 22-26 AWG |
| 22 | SSR Control | SSR-001 DC input (+) | 22-26 AWG |
| 23 | Blower TRIAC PWM (gate trigger) | BLW-CTRL-001 PWM in | 22-26 AWG |
| 4 | Zero-cross interrupt input | BLW-CTRL-001 ZC out | 22-26 AWG |
| 34 | ADC: CT current sense (airflow interlock) | CT-001 burden / bias network | 22-26 AWG shielded |
| USB | Serial data | Host PC (Artisan) | USB cable |

## Bill of Electrical Materials (schematic-specific)

| Ref | Component | Value | Package | Notes |
|-----|---|---|---|---|
| BLW-CTRL-001 | TRIAC dimmer module | 8A AC, ZC detect | RobotDyn-style PCB | Phase-angle blower control (DR-011) |
| CT-001 | Current transformer | ZMCT103C 5A | Split-core, PCB-mount | Airflow interlock — RMS sensed on GPIO 34 (DR-011) |
| FILT-001 | AC line filter | X+Y cap module | Inline | Conducted-EMI suppression on motor leads (DR-011) |
| FERR-001 | Snap-on ferrite cores | Mixed dia. (4–10 mm cable) | Clamp-on | Motor leads + TC SPI cables (DR-011) |
| BOND-001 | Earth bond lug + ring terminal | M4 or #8 | Hardware | Motor frame → mains earth (DR-011) |
| Q2 | NPN transistor | 2N2222 or similar | TO-92 | SSR drive buffer (E7) — 5V to SSR |
| R3 | SSR buffer base resistor | 1k ohm | 1/4W axial | Limits base current for Q2 (E7) |
| R-SNB | Snubber resistor | 47 ohm | 2W | Across SSR output (E10) |
| C-SNB | Snubber capacitor | 0.01 µF / 400V | X2-rated film | Across SSR output (E10) |
| THFUSE-002 | Thermal fuse (airstream) | 192–216°C | Axial | In-airstream backup (E6) |

**Removed by DR-011:** Q1 (IRLZ44N MOSFET), R1 (100 Ω gate), R2 (10 kΩ pulldown),
D1 (SS34 flyback). All were 12 V DC blower drive parts; not needed with the
TRIAC-controlled AC motor.

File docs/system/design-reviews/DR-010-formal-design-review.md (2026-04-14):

# DR-010: Formal Design Review — v1 Fluid-Bed Coffee Roaster

**Date:** 2026-04-12
**Disposition date:** 2026-04-13
**Status:** REVIEW DISPOSITIONED — All findings addressed. A1 and A2 rejected; all others incorporated.
**Review type:** Multi-panel design review (electrical safety, thermal/airflow, firmware, mechanical, alternatives)
**Scope:** Full system architecture, firmware, BOM, and build approach

---

## Executive Summary

The design is architecturally sound and well-documented for a v1 prototype. The
air path, power domain separation, sensor strategy, and iterative philosophy are
all well-reasoned. However, five review panels identified **8 critical findings**,
**13 major findings**, and **12 minor findings** that should be addressed before
powered testing.

The three highest-priority actions are:
1. **Add a hardware watchdog** that independently de-energizes the heater if the
   ESP32 stops responding
2. **Fix the firmware safety bugs** (NAN bypass, airflow interlock, startup race,
   forced_off latch)
3. **Verify blower P-Q performance** before committing to any other component sizing

A significant simplification opportunity exists: **use the intact heat gun body
as the heater can** and **consider a PID controller for v1 controls**, deferring
the ESP32 instrumentation system to v1.5.

---

## Review Panel Reports

### Panel 1: Electrical Safety

| # | Finding | Severity | Action |
|---|---|---|---|
| E1 | No hardware watchdog — ESP32 hang leaves 1500W heater energized | CRITICAL | Add external WDT (TPL5010 or MAX6369) or enable ESP32 TWDT; must independently de-energize SSR |
| E2 | `safety_reset()` unconditionally clears fault state | CRITICAL | Gate on actual temp readings below safe threshold with hysteresis |
| E3 | `forced_off` flag never cleared — heater permanently disabled after any fault | CRITICAL | `safety_reset()` must clear `forced_off` only after validating safe conditions |
| E4 | No airflow interlock — heater can run with blower off | CRITICAL | Firmware: check `blower_is_running()` minimum. Hardware: tachometer or current sense |
| E5 | 15A fuse on 15A circuit with 13A continuous load (87% of rating, NEC requires ≤80%) | MAJOR | Use 20A circuit + 12 AWG cord, or limit heater to stay under 12A continuous |
| E6 | Thermal fuse on can body, not in airstream — thermal lag may delay trip in no-airflow scenario | MAJOR | Add second thermal fuse in the heated airstream; consider lower rating (192–216°C) |
| E7 | SSR drive at 3.3V is marginal for many commodity SSRs | MAJOR | Buffer with NPN/MOSFET to drive SSR from 5V rail, or verify specific SSR input curve |
| E8 | Single-pole disconnect — if cord polarity is reversed, switch doesn't isolate heater | MAJOR | Use double-pole disconnect switch |
| E9 | Flyback diode 1N5819 rated 1A, blower draws 1-2A | MINOR | Upgrade to SS34 (3A Schottky) |
| E10 | No RC snubber on SSR output | MINOR | Add 47Ω + 0.01µF/400V X2-rated across SSR output |
| E11 | `analogWrite()` on ESP32 defaults to ~1kHz, not the 25kHz stated in schematic | MINOR | Use explicit `ledcSetup()`/`ledcAttachPin()`/`ledcWrite()` for 25kHz PWM |
| E12 | `safety_init()` calls `heater_force_off()` at boot, permanently latching the forced_off flag | MINOR | Remove `heater_force_off()` from `safety_init()` — `heater_init()` already ensures safe state |
| E13 | SPI bus noise near 1500W burst-fire switching — single glitch triggers TC fault | MINOR | Add consecutive-fault counter (e.g., 3 bad reads) before declaring fault; use shielded cable |

### Panel 2: Thermal & Airflow Engineering

| # | Finding | Severity | Action |
|---|---|---|---|
| T1 | Blower P-Q performance unverified — 120mm×32mm 12V centrifugal may not deliver 13-15 CFM at 2" WC | CRITICAL | **Measure actual blower P-Q curve before committing to any other sizing** |
| T2 | Plenum single-baffle design unlikely to equalize pressure — 5-10× velocity ratio at inlet | MAJOR | Add second baffle or perforated diffusion plate inside plenum; validate in TP-001 |
| T3 | 2.5" tube L/D ratio ~1.0 risks slugging (Geldart D particles slug at L/D > 0.5-0.8) | MAJOR | 3.0" tube is better geometry (L/D ~0.57) but has thermal budget issues |
| T4 | 3.0" chamber cannot reach 200°C ΔT after 100-230W parasitic losses on 1500W heater | MAJOR | Insulate heater can and plenum; or accept 160-175°C process air (slower roasts) |
| T5 | 1.5× Umf operating margin is thin; hot-air density corrections inconsistently applied | MAJOR | Target 1.8-2.5× Umf; recompute all velocities at process temperature |
| T6 | Moisture release during roasting absorbs ~30-40W equivalent (unaccounted) | MINOR | Not fatal; document as known loss |
| T7 | Bean mass changes 12-18% during roasting, altering fluidization velocity requirements | MINOR | Monitor and adjust blower mid-roast; document expected behavior |
| T8 | 30×30 mesh may clog with chaff oils, progressively increasing back-pressure | MINOR | Plan for mid-roast mesh cleaning or use coarser mesh |

### Panel 3: Firmware Architecture

| # | Finding | Severity | Action |
|---|---|---|---|
| F1 | NAN bypasses overtemp check — `NAN > 280.0f` is `false` per IEEE 754 | CRITICAL | Guard: `if (isnan(tc1) \|\| tc1 > SAFETY_MAX_PROCESS_TEMP_C)` |
| F2 | No hardware watchdog — ESP32 hang leaves SSR in last state | CRITICAL | Enable ESP32 TWDT with 2-5s timeout; feed in main loop |
| F3 | No airflow interlock in firmware | CRITICAL | Add `blower_is_running()` check to `safety_check()` |
| F4 | Startup race — all TCs start faulted, safety_check() faults immediately, forced_off latches permanently | CRITICAL | Init safety first; add startup grace period (N good reads before allowing heater) |
| F5 | `forced_off` never cleared by `safety_reset()` | MAJOR | Clear `forced_off` in `safety_reset()` only after validating conditions |
| F6 | Stale sensor data — safety checks 249ms-old data in worst case | MAJOR | Poll sensors every loop, or timestamp and reject stale readings |
| F7 | No rate-of-change detection (dT/dt) for runaway detection | MAJOR | Track previous temp; fault if rate exceeds configurable threshold (e.g., >10°C/s) |
| F8 | `safety_reset()` always succeeds — no condition validation | MINOR | Gate on actual temperatures and fault states |
| F9 | Command buffer overflow — 64-byte fixed buffer with no explicit overflow handling | MINOR | Discard input beyond 63 chars; low risk (requires physical access) |

### Panel 4: Mechanical & Fabrication

| # | Finding | Severity | Action |
|---|---|---|---|
| M1 | Overall base stability — tall asymmetric assembly will tip over | CRITICAL | Widen baseplate to 20"+ in blower direction; add ballast weight; add L-brackets |
| M2 | 2-3" hole in 22ga pan wall weakens structure and deforms under hose clamp | MAJOR | Add short stub tube through hole; use two hose clamps (inside + outside) |
| M3 | Bolted ring on rolled rim — concentrates force, will crush rim at bolt holes | MAJOR | Use fender washers + backing strips; torque gently (hand-tight + ¼ turn) |
| M4 | Chamber tube held by gravity only — 12" tube will tip under vibration or bump | MAJOR | Add 3 set screws through clamping ring, or spring clips, or friction-fit gasket wrap |
| M5 | Heater can construction undefined — riskiest fabrication step | MAJOR | Build from 2.5" exhaust pipe; mount element via mica former tabs; insulate exterior |
| M6 | Expansion chamber to chamber tube transition undefined | MAJOR | Fabricate sheet metal cone reducer; hose clamp at each end |
| M7 | Pan may have organic residue/burnishing compounds | MINOR | Burn off outdoors at full temp for 10 min before first use with beans |
| M8 | Gasket: ceramic fiber sheds respirable fibers; fiberglass is safer | MINOR | Use fiberglass stove rope/tape instead of ceramic fiber |
| M9 | TC mounting needs positive sealing and strain relief | MINOR | Compression fittings (1/8" Swagelok-style, ~$3-5 each); cable tie strain relief |
| M10 | Thermal expansion at 250°C is ~0.4% on SS — non-issue with compliant gasket joints | MINOR | No action required |
| M11 | Hose clamps adequate at 2" WC — use all-stainless at temperature | MINOR | Specify all-stainless worm-drive clamps in BOM |

### Panel 5: Alternative Approaches

| # | Recommendation | Impact | Effort Saved |
|---|---|---|---|
| A1 | **Use intact heat gun body as heater can** — skip element extraction, keep factory thermal cutout in circuit | Eliminates heater can fabrication (M5), retains independent safety device | Significant — removes riskiest fabrication and adds free safety backup |
| A2 | **Consider PID controller (Inkbird ITC-100VH, ~$30) for v1 controls** — proven over-temp protection, no firmware to debug | Defers all firmware development; removes F1-F9 as blockers to first roast | Very significant — weeks of firmware work deferred |
| A3 | **Consider borosilicate glass tube as v1 chamber** — visual feedback accelerates learning | Can see fluidization quality and roast color development in real time | Low effort change; glass tube ~$5-10 |
| A4 | **Roast on a popcorn popper first** to calibrate senses before building | Teaches fluidization feel, first-crack sound, roast progression for ~$10 | Minimal; should happen regardless |

---

## Consolidated Action Items — Priority Order

### Must Fix Before Powered Testing

1. **Hardware watchdog** (E1, F2) — Add external WDT or enable ESP32 TWDT. The
   SSR must de-energize if firmware hangs. This is the single most important safety gap.

2. **NAN bypass bug** (F1) — Add `isnan()` guard to every temperature comparison
   in `safety_check()`. 10-minute fix that prevents the most dangerous firmware bug.

3. **Airflow interlock** (E4, F3) — At minimum, check `blower_is_running()` before
   allowing heater. Better: tachometer or current sense on the blower.

4. **Startup race condition** (F4) — Reorder `setup()` to init safety first. Add
   startup grace period requiring N consecutive good TC reads before heater enable.

5. **Fix forced_off latch** (E3, F5) — `safety_reset()` must clear `forced_off`
   only after validating temps are below threshold and TCs are reading clean.

6. **Blower P-Q verification** (T1) — Get the blower, measure its actual flow vs.
   pressure curve. Everything else depends on this number.

7. **Base stability** (M1) — Design a stable base before energizing anything.
   Wider footprint, ballast weight, lateral bracing.

### Should Fix Before First Roast

8. **Fusing margin** (E5) — Resolve 15A/15A issue (use 20A circuit or limit
   continuous heater current).

9. **SSR drive buffer** (E7) — Add NPN/MOSFET buffer for reliable 5V SSR drive.

10. **Double-pole disconnect** (E8) — Replace single-pole switch with DPST.

11. **Thermal fuse placement** (E6) — Add second thermal fuse in airstream.

12. **Plenum equalization** (T2) — Plan for a second baffle; validate in TP-001.

13. **Chamber tube retention** (M4) — Set screws or clips; never gravity alone.

14. **Stub tube for plenum side-entry** (M2) — Prevent pan wall deformation.

15. **Clamping ring load spreading** (M3) — Fender washers and backing strips.

16. **Expansion chamber mounting** (M6) — Sheet metal cone reducer.

17. **Heater can build plan** (M5) — Or adopt alternative A1 (intact heat gun body).

18. **Rate-of-change detection** (F7) — dT/dt check in safety layer.

19. **Stale sensor data** (F6) — Poll sensors every loop iteration.

20. **SPI noise resilience** (E13) — Consecutive-fault counter before tripping.

### Consider for Significant Simplification

21. **Use intact heat gun as heater can** (A1) — Eliminates riskiest fabrication,
    retains factory thermal cutout as independent safety backup.

22. **PID controller for v1 controls** (A2) — Defers all firmware as a blocker to
    first roast. ESP32 system developed in parallel, swapped in for v1.5.

23. **Glass chamber for v1** (A3) — Visual feedback on fluidization and roast
    development accelerates learning significantly.

24. **Roast on a popper first** (A4) — Calibrate senses before building.

---

## Review Process

This review was conducted using a five-panel structure designed to be repeatable
at future design gates:

| Panel | Scope | Key Question |
|---|---|---|
| Electrical Safety | Power path, grounding, protection, SSR failure modes | Will this shock or electrocute someone? Will it start a fire? |
| Thermal & Airflow | Fluidization, heat transfer, pressure drops, blower sizing | Will the physics actually work? Are the calculations right? |
| Firmware | Safety logic, sensor handling, timing, fault modes | If the software fails, what happens to the hardware? |
| Mechanical | Buildability, structural integrity, thermal tolerance | Can this be built with available tools? Will it hold together? |
| Alternatives | Simpler/safer/cheaper approaches from existing practice | Are we over-engineering where a simpler solution exists? |

**To repeat this review** at DG-1 or later gates, provide the updated design
documents to each panel with the same scope questions. Focus on:
- Findings marked "validate in TP-00X" — were they validated?
- Action items from this review — were they implemented?
- New design decisions since DR-010 — do they introduce new risks?

---

## Appendix: Finding Count Summary

| Severity | Electrical | Thermal | Firmware | Mechanical | Total |
|---|---|---|---|---|---|
| CRITICAL | 4 | 1 | 4 | 1 | **10** |
| MAJOR | 4 | 4 | 3 | 5 | **16** |
| MINOR | 5 | 3 | 2 | 5 | **15** |
| **Total** | **13** | **8** | **9** | **11** | **41** |

Note: Some findings overlap between panels (e.g., hardware watchdog appears in
both Electrical and Firmware panels). The consolidated action list de-duplicates these.

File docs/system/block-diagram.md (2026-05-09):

# System Block Diagram

## Overview

This document defines the system-level architecture for the v1 fluid-bed coffee roaster.
All subsystem boundaries and interfaces are defined here. Downstream design work
(mechanical, electrical, firmware) must be consistent with these diagrams.

---

## Air Path

The process airflow is the core physical system. Everything else exists to support,
control, and measure this flow.

```mermaid
flowchart LR
    A[Ambient Air] --> B[Blower]
    B --> C[Heater Can]
    C -->|Side Entry| D["Plenum\n(8in dia x 6in tall round stovepipe, DR-012)"]
    D --> E["Deflector Ramp\n(45° SS baffle)"]
    E --> E2["Second Baffle\n(perforated, if needed)\n(T2)"]
    E2 --> F["Distributor Plate\n(bolted clamping ring)"]
    F --> G[Roast Chamber]
    G --> H[Expansion Chamber\n~4in OD x 5in tall SS]
    H --> J[30x30 SS Mesh Screen]
    J --> I[Exhaust Out]

    style F fill:#f96,stroke:#333
    style D fill:#69f,stroke:#333
    style H fill:#f9f,stroke:#333
```

### Air Path Notes

| Segment | Key Parameter | Design Concern |
|---|---|---|
| Blower → Heater Can | Airflow rate (CFM), static pressure | Hose clamp joint (not welded) to preserve future bypass option (DR-005) |
| Heater Can | Air temperature rise | Element must fit the can; air must contact element long enough for heat transfer |
| Heater Can → Plenum | Side-entry velocity | High inlet velocity must be tamed by plenum + baffles |
| Plenum + Baffles | Pressure equalization | Convert directional jet to uniform pressure field. T2: plan for second baffle if single ramp insufficient |
| Distributor Plate | Velocity uniformity | Critical tuning component — must be swappable for iteration |
| Roast Chamber | Fluidization quality | Even bed motion, no dead zones, no geysering. M4: chamber tube retained by set screws or clips, not gravity alone |
| Expansion Chamber | Chaff separation by velocity drop | Step-up from chamber dia to ~4" OD drops velocity to 2-4 ft/sec; chaff settles (DR-006) |
| Mesh Screen | Secondary chaff capture | 30×30 SS mesh; removable for cleaning between roasts |
| Exhaust | Backpressure budget | Expansion chamber + mesh must not restrict flow enough to impede fluidization |

### Cooling Mode (DR-005)

During cooling: SSR off (heater 0%), blower 100%. Air path remains serial
(Blower → Heater Can → Plenum → Chamber). Residual heater thermal mass
(~13-23 kJ) dissipates in ~15-30 seconds at 10-15 CFM forced convection.
Target: beans from ~200°C to <50°C within 140 seconds.

The blower-to-heater-can joint is a hose clamp connection, not welded. If
TP-002 data shows thermal lag is unacceptable, the heater can can be physically
disconnected for bypass cooling, or a diverter added later.

---

## Power Path

```mermaid
flowchart TD
    MAINS["120V AC Mains"] --> DISC["Hard Disconnect\n(switch or plug)"]
    DISC --> FUSE["Fuse / Breaker\n(15A)"]
    FUSE --> BUS["AC Power Bus"]

    subgraph DOMAIN1["Domain 1: 120V AC — Heater (Mains)"]
        BUS --> SSR["Zero-Cross SSR"]
        SSR --> HTR["Heater Element\n(Warrior 1500W nichrome)"]
    end

    subgraph DOMAIN2["Domain 2: 120V AC — Blower (DR-011)"]
        BUS --> FILT["AC Line Filter\n(FILT-001)"]
        FILT --> CT["Current Transformer\n(ZMCT103C — CT-001)"]
        CT --> TRIAC["TRIAC Dimmer\n(BLW-CTRL-001)"]
        TRIAC --> BLWR["Bypass-Cooled\nUniversal-AC Vacuum Motor\n(BLW-001)"]
    end

    subgraph DOMAIN3["Domain 3: 3.3V DC — Controls"]
        BUS --> PSU3["3.3V/5V PSU\n(USB or regulator)"]
        PSU3 --> ESP["ESP32 + Control Board"]
    end

    ESP -->|"GPIO 23 (PWM in)"| TRIAC
    TRIAC -->|"GPIO 4 (ZC out)"| ESP
    CT -->|"GPIO 34 (ADC sense)"| ESP
    ESP -->|"GPIO 22"| SSR

    style SSR fill:#f66,stroke:#333
    style DISC fill:#ff9,stroke:#333
    style DOMAIN1 fill:#fee,stroke:#c33
    style DOMAIN2 fill:#eef,stroke:#33c
    style DOMAIN3 fill:#efe,stroke:#3c3
```

### Power Path Notes

- **Two mains-side domains + one LV domain (DR-011):** 120V AC heater, 120V AC blower
  via TRIAC, 3.3V DC controls.
- Hard disconnect is **mandatory** — must be reachable during operation
- Fuse sized for total load: heater (~12.5A) + blower motor (~1–4A) + 5V PSU (<1A) at 120V.
  Total can exceed the 15A budget if both heater and blower run at full duty — verify
  combined draw at TP-001 and limit blower-during-heat duty if needed.
- SSR is controlled by ESP32 via zero-cross switching for burst-fire duty control
- **Blower (DR-011):** Aftermarket Lamb 116336-01-pattern universal-AC bypass-cooled vacuum motor, phase-angle
  speed control via a TRIAC dimmer module. ESP32 fires the gate per zero-cross
  interrupt. Airflow interlock via ZMCT103C current transformer on a motor lead.
- **Bypass-cooled motor required** — flow-through motors put brush carbon dust into
  the bean airstream.
- 5V PSU must be isolated from mains; ESP32 side is entirely low-voltage
- **All metal chassis components must be grounded to mains earth, including the
  blower motor frame** (BOND-001) — universal motors have nontrivial leakage current
- AC line filter (FILT-001) and snap-on ferrites (FERR-001) are mandatory to
  contain TRIAC + brushed-motor conducted EMI from corrupting TC SPI signals

---

## Signal Path

```mermaid
flowchart TD
    subgraph Sensors
        TC1["TC1: Process Air\n(K-type)"]
        TC2["TC2: Bean Bed\n(K-type)"]
        TC3["TC3: Exhaust\n(K-type)"]
    end

    subgraph TC_Interface["TC Amplifiers"]
        AMP1["MAX31855 #1"]
        AMP2["MAX31855 #2"]
        AMP3["MAX31855 #3"]
    end

    TC1 --> AMP1
    TC2 --> AMP2
    TC3 --> AMP3

    subgraph MCU["ESP32"]
        SPI["SPI Bus"]
        GPIO_SSR["GPIO → SSR Control"]
        GPIO_BLWR["GPIO → Blower Control"]
        SAFETY["Safety Layer"]
        CTRL["Control Layer"]
        LOG["Logging Layer"]
    end

    AMP1 -->|SPI + CS1| SPI
    AMP2 -->|SPI + CS2| SPI
    AMP3 -->|SPI + CS3| SPI

    SPI --> SAFETY
    SPI --> CTRL
    SPI --> LOG

    SAFETY -->|Override| GPIO_SSR
    CTRL --> GPIO_SSR
    CTRL --> GPIO_BLWR

    GPIO_SSR --> SSR["SSR Gate"]
    GPIO_BLWR --> BDRV["TRIAC Dimmer\n(phase-angle, ZC-synced)"]

    style SAFETY fill:#f66,stroke:#333
    style CTRL fill:#6f6,stroke:#333
    style LOG fill:#69f,stroke:#333
```

### Signal Path Notes

- Three MAX31855 breakout boards share a single SPI bus with individual chip-select lines
- SSR control is a single GPIO (logic-level, active high assumed until schematic finalized)
- Blower control: ESP32 GPIO 23 drives the TRIAC dimmer's PWM input; GPIO 4 reads
  the dimmer's zero-cross output as an interrupt; GPIO 34 ADC-samples the CT-001
  current transformer for the airflow interlock (DR-011)
- **Safety layer has hardware-priority override on SSR GPIO** — it can force heater off regardless of control layer state
- All signal wiring must be physically separated from mains wiring; TC SPI cables
  require snap-on ferrites and shielded jacket to survive brushed-motor + TRIAC EMI

---

## Data Path

```mermaid
flowchart LR
    ESP32["ESP32"] -->|Serial / USB| PC["Host PC"]
    PC --> ARTISAN["Artisan\nRoast Logger"]

    ESP32 -.->|"Future: WiFi/TCP"| PC

    subgraph Data_Stream["Data Stream (2+ Hz)"]
        direction TB
        D1["TC1 (°C)"]
        D2["TC2 (°C)"]
        D3["TC3 (°C)"]
        D4["Heater Cmd (%)"]
        D5["Blower Cmd (%)"]
        D6["State / Faults"]
        D7["Timestamp (ms)"]
    end

    ESP32 --- Data_Stream
```

### Data Path Notes

- v1 primary interface: **USB serial** at 115200 baud (or as Artisan requires)
- Protocol: Modbus TCP or Artisan serial protocol (to be specified in `docs/software/artisan-integration.md`)
- Minimum sample rate: **2 Hz** per channel (Artisan expects 1-3 second intervals)
- Future option: ESP32 WiFi for wireless logging (same data format, TCP transport)
- All data fields are logged even in manual mode — this is the characterization dataset

---

## Subsystem Boundary Summary

| Subsystem | Inputs | Outputs | Interface Owner |
|---|---|---|---|
| Blower | 120V AC via TRIAC, conduction-angle speed command, ZC sync | Airflow + pressure | Electrical → Mechanical |
| Blower current sense | Motor lead AC current (ZMCT103C primary) | RMS reading for airflow interlock | Electrical → Firmware |
| Heater Can | Airflow, AC power via SSR | Heated airflow | Electrical → Mechanical |
| Plenum + Plate | Heated airflow (side entry) | Uniform upward velocity | Mechanical |
| Roast Chamber | Uniform hot air, green beans | Roasted beans, hot exhaust + chaff | Mechanical |
| Expansion Chamber | Hot air + chaff | Separated chaff, slower air | Mechanical |
| Mesh Screen + Exhaust | Slow air with residual chaff | Clean exhaust out | Mechanical |
| TC Sensors (x3) | Physical temperature | SPI digital readings | Electrical → Firmware |
| ESP32 Control | Sensor data, operator commands | SSR duty, blower command, data stream | Firmware |
| Safety System | Sensor data, fault signals | Override commands, fault latch | Firmware (authoritative) |
| Artisan Interface | Serial data stream | Roast logs, visualization | Firmware → Host PC |

---

## Cross-Reference

- Mechanical details: `docs/mechanical/`
- Electrical schematic: `docs/electrical/`
- Firmware architecture: `docs/software/firmware-architecture.md`
- Safety logic: `docs/software/safety-logic.md`
- Artisan protocol: `docs/software/artisan-integration.md`

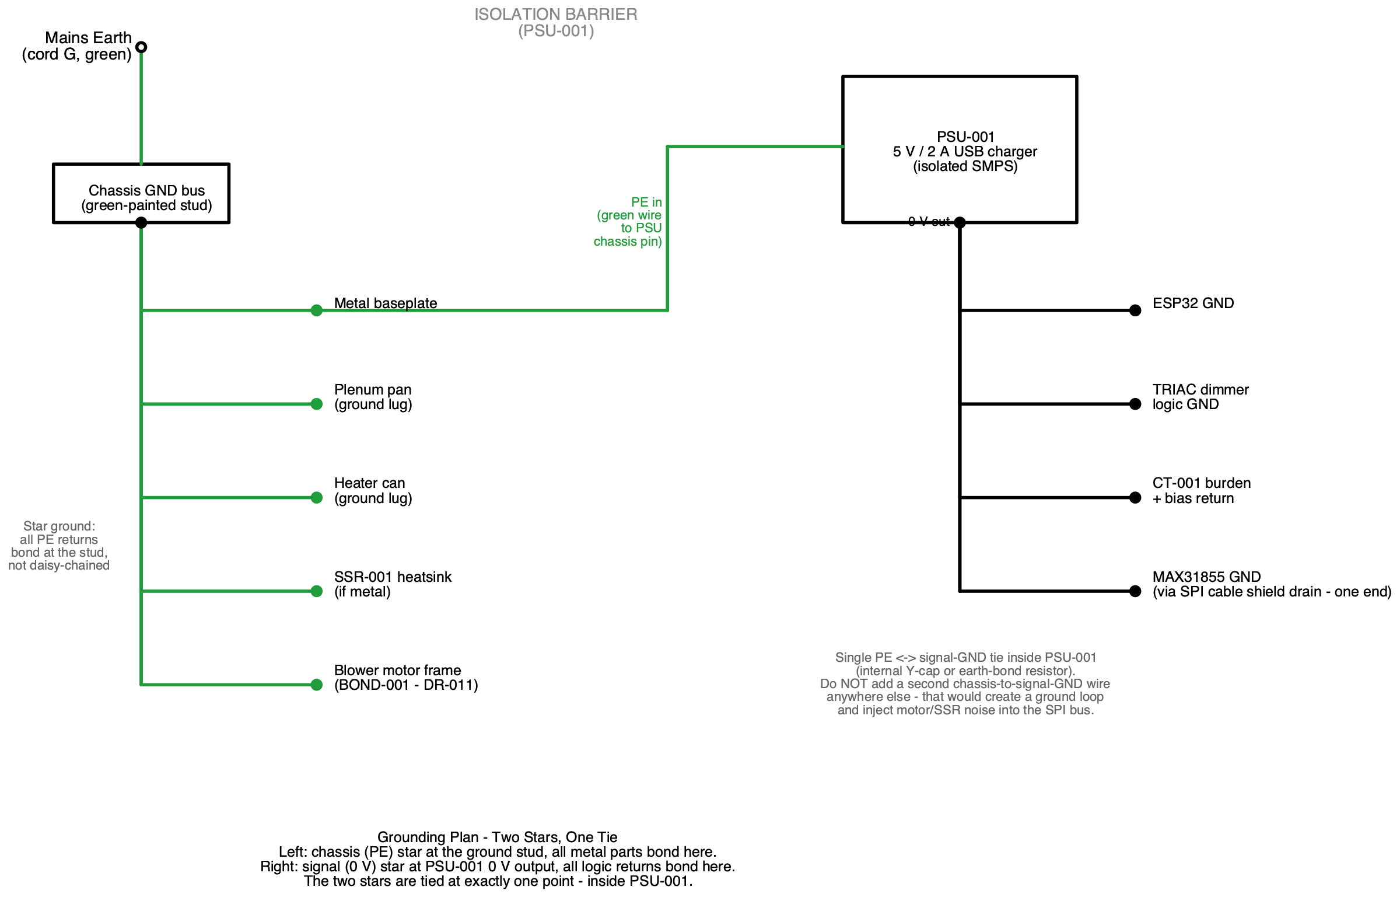
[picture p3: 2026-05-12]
docs/electrical/schematics/schemdraw/out/05_grounding.png

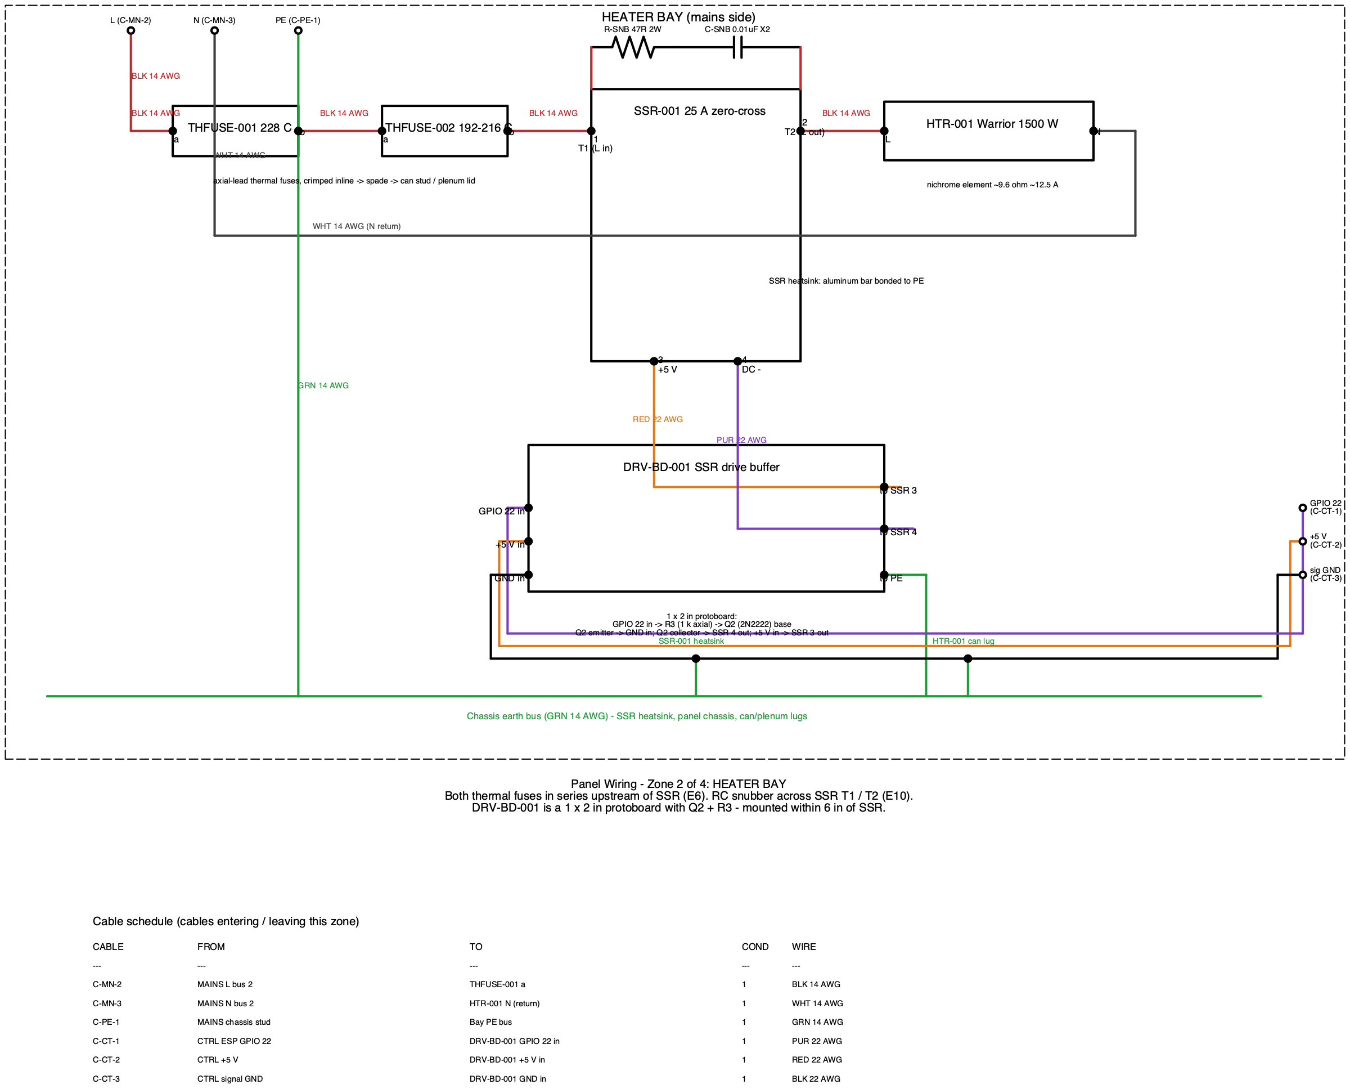
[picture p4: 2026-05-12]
docs/electrical/schematics/schemdraw/out/07_panel_heater_bay.png

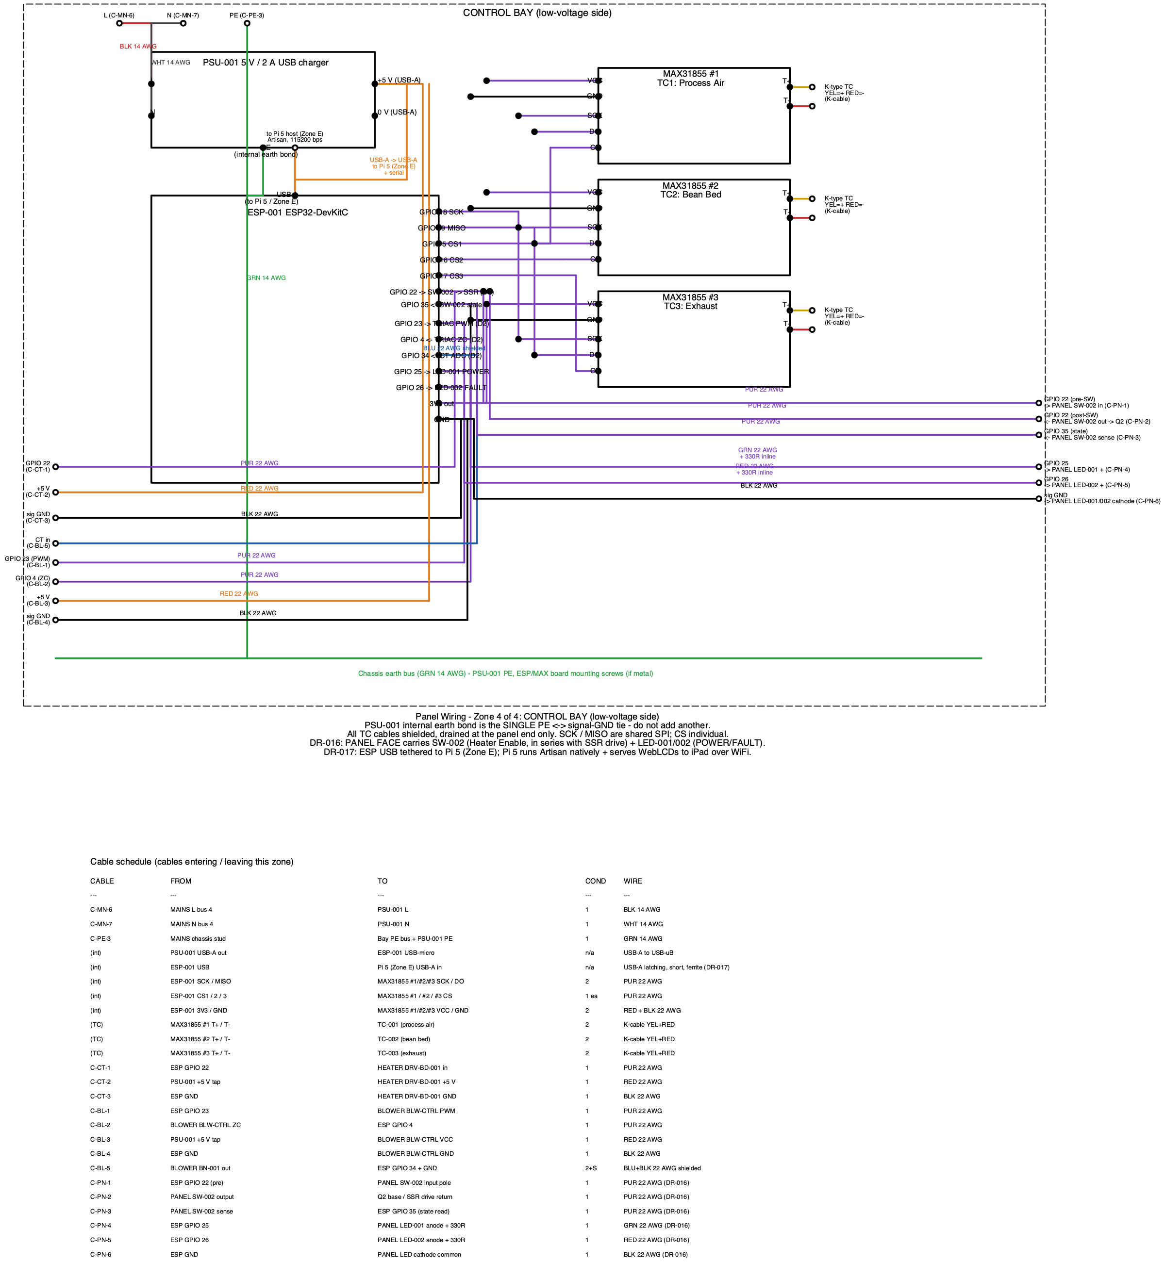
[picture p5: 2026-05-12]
docs/electrical/schematics/schemdraw/out/09_panel_control_bay.png

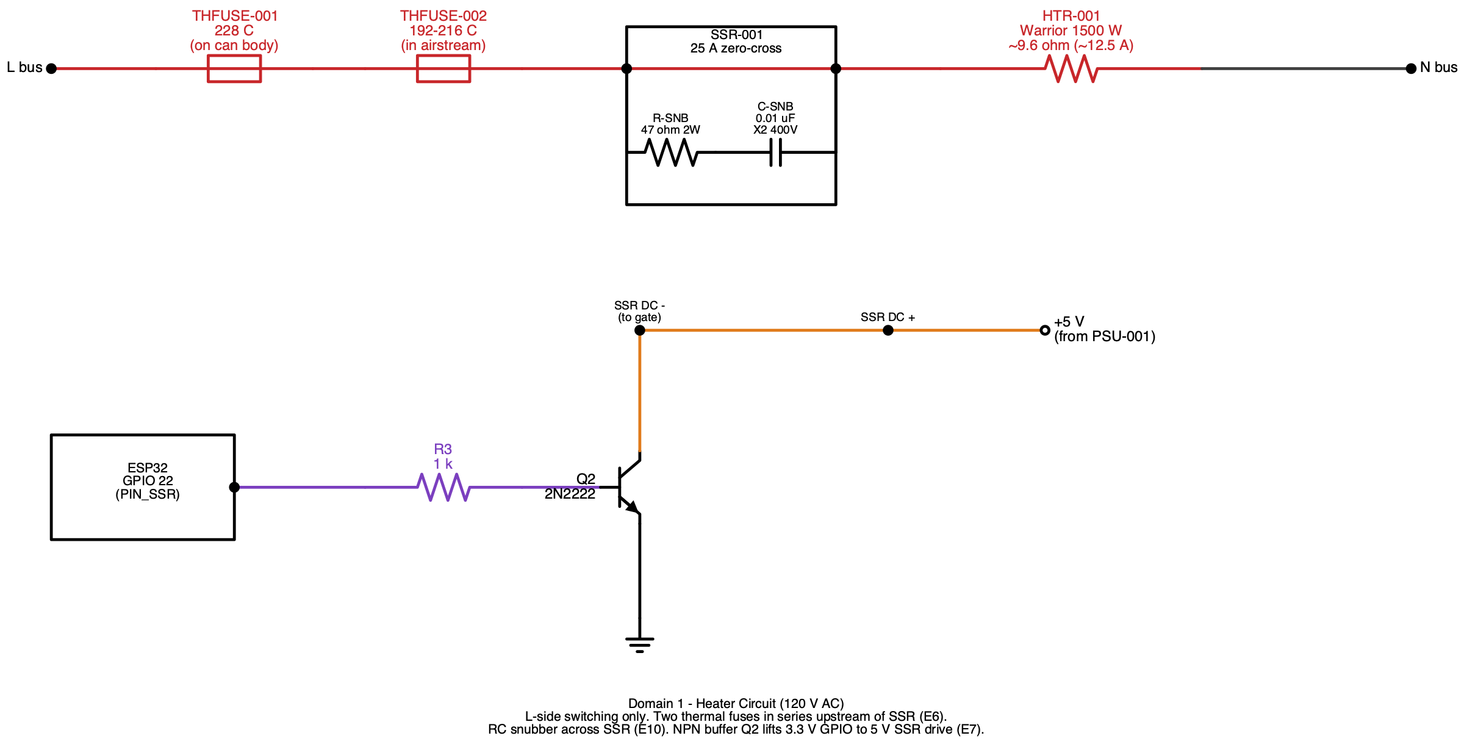
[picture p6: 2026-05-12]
docs/electrical/schematics/schemdraw/out/02_heater_circuit.png

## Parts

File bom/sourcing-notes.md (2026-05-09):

# Sourcing Notes

## Cost Strategy

Per DR-001: thrift and adapt where we can. Design around available cheap parts
rather than specifying ideal parts and paying catalog prices. See
`docs/system/design-reviews/DR-001-cost-strategy.md` for full rationale.

**Target v1 BOM: $75-125** (revised upward from $50-80 after DR-010 additions)

## Status Key
- **Needs selection** — specification not yet finalized
- **Needs sourcing** — spec known, vendor/part number needed
- **Thrift hunt** — go find one at a thrift store / junk drawer
- **Ordered** — part ordered, awaiting delivery
- **In hand** — part received and verified
- **Installed** — part built into the machine

## Sourcing Priority Order

Source parts in this order because downstream geometry depends on upstream finds:

0. **Popcorn popper** (thrift store, ~$2-5) — A4: Roast on a popper first to
   calibrate operator senses before building. Do this while sourcing other parts.
   Any hot-air popcorn popper works (West Bend Poppery, Presto PopLite, etc.).

1. **Warrior heat gun** (Harbor Freight, SKU 56434, ~$10) — heater element donor.
   Nichrome on mica former, 1500W, dual-temp. Get this first, tear down, measure
   element resistance and geometry, then design heater can around it. The heat
   gun housing is NOT retained (A1 rejected) — extract element and thermal cutout.
   See DR-002.

2. **Blower — bypass-cooled vacuum motor (salvage)** — DR-011 supersedes DR-003.
   Hunt at Habitat ReStore, Goodwill, or curb pickup for a dead/cheap shop vac
   with a **bypass / two-stage** motor (separate cooling impeller from working
   impeller — flow-through motors shed brush carbon into the bean airstream).
   Inspect dual-airpath separation before committing. Pair with these new
   line items, all on the AC side:
   - **BLW-CTRL-001** TRIAC dimmer module (RobotDyn-style 8A with on-board
     zero-cross detector), Amazon ~$5–10
   - **CT-001** ZMCT103C 5A split-core CT module for the airflow interlock,
     Amazon ~$3–8
   - **FILT-001** AC line filter (X+Y caps inline), Amazon or salvaged from
     a dead PC PSU input stage
   - **FERR-001** snap-on ferrite chokes (mixed-bore set), Amazon ~$5
   - **BOND-001** earth bonding lug for motor frame, hardware store ~$1

   The 12V/3A switching PSU (PSU-002), MOSFET (Q1-001), gate resistors
   (R1/R2-001), and flyback diode (D1-001) are no longer required and have
   been deleted from the BOM.

3. **Chamber tubes** (auto parts store or online) — 2.5" and 3.0" OD SS exhaust
   pipe. Standard sizes, easy to find. Also source a 3.0" OD borosilicate glass
   tube (A3) from Amazon or lab supply (~$5-10) for visual fluidization testing.

4. **Plenum pan** (restaurant supply or thrift store) — 1/6 size SS steam table
   pan, 4" deep. ~$4-8 new from WebstaurantStore, Chef's Deal, or local
   restaurant supply. At thrift stores look for any small rectangular SS pan
   with straight walls and at least 3" depth. M7: Burn off outdoors at full
   temp for 10 min before first use. See DR-007.

5. **Electronics** (Amazon) — ESP32, MAX31855 x3, SSR, TCs, compression
   fittings (M9), plus DR-010 + DR-011 additions:
   - NPN transistor 2N2222 + 1k base resistor (E7: SSR drive buffer)
   - 47Ω 2W resistor + 0.01µF/400V X2 film cap (E10: RC snubber)
   - Second thermal fuse 192-216°C (E6: airstream backup)
   - Shielded cable for SPI bus runs near heater (E13)
   - **DR-011 blower-control kit:** TRIAC dimmer (BLW-CTRL-001), ZMCT103C
     current sensor (CT-001), AC line filter (FILT-001), snap-on ferrite
     chokes (FERR-001), motor frame bonding lug (BOND-001)
   These are spec-driven and can be ordered in parallel with steps 1-4.

6. **Hardware store run** — fuse, DPST disconnect switch (E8: double-pole, not
   single-pole), strain reliefs, wire (14 AWG; 12 AWG if using 20A circuit per
   E5), connectors, fasteners (including fender washers and backing strips per
   M3), all-stainless hose clamps (M11).

7. **Baseplate materials** (BASE-001 — sourced/cut). 12"×18" steel deck cut
   from 12"×24" sheet stock 2026-05-07. Remaining stock + offcuts feed the
   1"-class angle-iron frame (perimeter + rear motor extension + front
   electronics-tray extension) per baseplate-layout.md §1. Tripod tip
   resistance via DR-013 threaded-rod legs (LEGS-001) supersedes the original
   L-bracket / ballast plan.

## Sourced Amazon Parts (validated 2026-04-28; DR-011 additions validated 2026-04-29)

All Amazon URLs below were validated by HTTP 200 fetch on the dates noted.
Cross-referenced against search-result titles to confirm product match.
Amazon ASINs and listings change — re-validate before placing the order.

DR-011 (2026-04-29) removed BLW-001, Q1-001, D1-001, and PSU-002 from this
table — they were 12V DC blower components that are no longer needed. The
new DR-011 line items (BLW-CTRL-001, CT-001, FILT-001, FERR-001) have been
validated and added to the Electronics table below. BOND-001 is hardware
store only — no Amazon listing.

### Electronics

| BOM Item | Listing | ASIN |
|---|---|---|
| ESP-001 | HiLetgo ESP-WROOM-32 dev board (single) | [B0718T232Z](https://www.amazon.com/dp/B0718T232Z) |
| TC-AMP-001 (×3) | NOYITO MAX31855 K-type breakout | [B07K5MJ43M](https://www.amazon.com/dp/B07K5MJ43M) |
| SSR-001 | SSR-25DA 25A zero-cross 3-32VDC / 24-380VAC | [B07FVR37QN](https://www.amazon.com/dp/B07FVR37QN) |
| Q2-001 | OCR 2N2222/2N3904 etc. TO-92 transistor kit | [B071KK9B3H](https://www.amazon.com/dp/B071KK9B3H) |
| R3-001 | ELEGOO 525-pc 1/4 W 1% resistor kit (covers 1 k and many other values) | [B072BL2VX1](https://www.amazon.com/dp/B072BL2VX1) |
| R-SNB-001 | uxcell 47 Ω 2 W metal-oxide flame-proof (60-pack) | [B07V2NV3P9](https://www.amazon.com/dp/B07V2NV3P9) |
| C-SNB-001 | 0.01 µF 275 VAC X2 safety film cap | [B09JWZ5MWQ](https://www.amazon.com/dp/B09JWZ5MWQ) |
| THFUSE-001 | NEC SF240E SEFUSE 240 °C 10 A axial | [B015675DA8](https://www.amazon.com/dp/B015675DA8) |
| THFUSE-002 | AUPO BF192 192 °C 10 A axial (10-pack) | [B0FJ5WJM9Z](https://www.amazon.com/dp/B0FJ5WJM9Z) |
| WIRE-002 | TUOFENG 22 AWG silicone hookup wire (6 colors × 26 ft) | [B07G2JWYDW](https://www.amazon.com/dp/B07G2JWYDW) |
| CONN-001 | Sopoby 1200-pc insulated crimp-terminal assortment | [B01GAESOWA](https://www.amazon.com/dp/B01GAESOWA) |

### Electronics — DR-011 blower control kit (validated 2026-04-29)

| BOM Item | Listing | ASIN |
|---|---|---|
| BLW-CTRL-001 | Genuine RobotDYN PWM AC programmable light dimmer 110-220V w/ heatsink, 3.3V/5V logic | [B071X19VL1](https://www.amazon.com/dp/B071X19VL1) |
| CT-001 | HiLetgo 3-pc ZMCT103C 5A AC current sensor w/ onboard op-amp + bias (single-phase, voltage output) | [B0CDWWYLMQ](https://www.amazon.com/dp/B0CDWWYLMQ) |
| FILT-001 | uxcell CW4L2-10A-T AC EMI filter 115/250 V 10 A (chassis-mount, terminal block, X+Y caps) | [B016EISSGE](https://www.amazon.com/dp/B016EISSGE) |
| FERR-001 | IEUYO 22-pc clip-on ferrite kit, 5 sizes (3/5/7/9/13 mm bore) | [B07DPM44BV](https://www.amazon.com/dp/B07DPM44BV) |
| BOND-001 | Hardware store — M4 or #8 ring terminal + green/yellow 14 AWG pigtail | (no Amazon link) |

### Sensors

| BOM Item | Listing | ASIN |
|---|---|---|
| TC-001/002/003 (×3) | Industrial Q-K-01 K-type 6 in × 3 mm 316 SS quick-disconnect probe | [B078QS3NWP](https://www.amazon.com/dp/B078QS3NWP) |
| TC-FIT-001 (×3) | Pysrych 1/8 in OD × 1/8 in NPT 304 SS double-ferrule (2-pack — buy 2) | [B09FF7LRL6](https://www.amazon.com/dp/B09FF7LRL6) |

### Mechanical

| BOM Item | Listing | ASIN |
|---|---|---|
| CHAM-001C | SUNWO borosilicate cylinder 3 in dia × 8 in tall (open-end chimney) | [B06XJT46QL](https://www.amazon.com/dp/B06XJT46QL) |
| PLEN-001 (backup) | AmazonCommercial 1/6-size 4 in deep anti-jam SS hotel pan (2-pack) | [B083M4N3SJ](https://www.amazon.com/dp/B083M4N3SJ) |
| PLEN-004 | 1 in fiberglass woodstove gasket rope (7 ft) | [B01ETURR0M](https://www.amazon.com/dp/B01ETURR0M) |
| PLATE-001A/B | FengYoo 4 in dia round 304 SS perforated disc, 1/16 in holes (qty 2) | [B09SF15S47](https://www.amazon.com/dp/B09SF15S47) |
| EXH-002 | 30-mesh 304 SS woven wire screen 11.8 × 23.6 in | [B09VNSQGVH](https://www.amazon.com/dp/B09VNSQGVH) |

### Substitutions and decisions to flag

- **THFUSE-001 (228 °C → 240 °C).** 228 °C single-pieces are not stocked by major Amazon sellers; nearest in-stock single-piece axial is the NEC SEFUSE 240 °C. Both ratings are well below nichrome failure (~1400 °C) and cool-mass thermal runaway envelopes — 240 °C is conservative for a heater-can-body cutoff. Acceptable per the safety-critical substitution gate.
- **CHAM-001C (10–12 in target → 8 in actual).** 3 in OD × 10 in+ borosilicate at hobby price is essentially unavailable on Amazon; the SUNWO chimney glass is 8 in tall. Validate that 8 in still gives enough freeboard above the bean bed (~2 in deep when fluidized) before the chaff transition. If insufficient, alternatives are GreatGlas custom Pyrex/quartz, Wale Apparatus 5 ft tubing cut to length, or staying with the SS chamber and accepting no visual.
- **PLATE-001A/B hole size.** Pre-cut 4 in disc ships with 1/16 in (1.5 mm) holes — small. Open area is ~22 % which gives high pressure drop. Confirm fluidization at 12 CFM during T1; if dP is too high, substitute a coarser perforated sheet.
- **PLEN-001.** Restaurant-supply or thrift is still the preferred path (per DR-001). The Amazon AmazonCommercial 2-pack is listed as a backup only.
- **EXH-001.** No clean Amazon match for a 4 in × 5 in tall pure-SS cylinder at low cost. Plan to thrift a SS flatware caddy, utensil cylinder, or coffee tin.
- **CT-001 (active op-amp output vs passive burden).** Original spec language called for "burden + bias network" — the HiLetgo board ships with an onboard op-amp that converts the CT's 5 mA secondary to a buffered voltage signal already biased to mid-rail. This is *better* than a passive burden + divider for ADC sampling (lower output impedance, less susceptible to ADC sample-and-hold loading). Firmware reads voltage on GPIO 34 and computes RMS. No spec change required; flag only because the implementation differs from the literal wording.
- **FILT-001 (chassis-mount terminal block, not 2-lead inline).** Original spec language called for an "inline module." The CW4L2-10A-T is a chassis-mount filter with screw terminals — it sits in the mains path between fuse bus and TRIAC dimmer, but it is mechanically a chassis part with mounting flange and earth lug, not a 2-leaded inline component. The earth lug must be bonded to the chassis-ground bus (see baseplate-layout.md §5). Functionally equivalent; affects mounting only.

## Vendor Shortlist

### Thrift / Salvage
- Goodwill, Salvation Army, Habitat ReStore — popcorn poppers (A4), SS containers,
  stainless cookware. Dead/cheap shop vacs were the original BLW-001 sourcing path
  (DR-011), but BLW-001 was ultimately purchased as an aftermarket Lamb 116336-01-pattern
  motor on Amazon (B0F89ZQ23G).
- Junk drawer — USB phone chargers (5V PSU), USB cables, small electronics components
- Curb / free pickup — shop vacs are common discards; verify bypass-cooled motor type
  if pursuing for any future motor sourcing

### Online (cheap)
- Amazon — generic ESP32, MAX31855 breakouts, SSR, K-type TCs, compression fittings,
  perforated SS sheet, wire assortment kits, borosilicate glass tubes, 2N2222,
  SS34, film capacitors
- eBay — same as Amazon, sometimes cheaper for bulk/salvage electronics

### Auto Parts
- AutoZone, O'Reilly, Amazon — 2.5" and 3.0" stainless exhaust pipe straight sections

### Hardware / Electrical
- Home Depot, Lowes, Ace — wire (14 or 12 AWG), fuses, DPST disconnect switch,
  strain reliefs, ring terminals, junction boxes, fasteners, fender washers,
  all-stainless hose clamps, L-brackets
- Restaurant supply store — stainless steam table pans (plenum body candidates)

### Specialty
- McMaster-Carr — 1/8" Swagelok-style compression fittings for TC probes (M9),
  if Amazon options are poor quality
- Lab supply (Amazon or eBay) — borosilicate glass tubing 3.0" OD (A3)

## Substitution Policy

For v1, exact part numbers are less important than meeting the functional requirement
at minimum cost. Document any substitutions in the BOM Notes column.

**Exception:** Safety-critical items (fuse, mains wiring, grounding hardware,
thermal fuses, SSR, disconnect switch) must meet rated specifications. Do not
substitute with lower-rated parts to save money.

## What to measure when you find parts

### Warrior heat gun teardown (SKU 56434)
- Element resistance (calculate wattage: P = V²/R at 120V; expect ~9.6Ω for 1500W)
- Element physical dimensions (length, diameter, mica former shape)
- Thermal cutout specs (temperature rating, one-shot vs resettable)
- Mica former tab locations (M5: needed for mounting in custom heater can)
- Note: the heat gun's built-in axial fan is not being used (DR-003 / DR-011)
- Note: the heat gun housing is not being retained (A1 rejected)

### Vacuum motor characterization (DR-011 — supersedes T1)

T1 changed from "verify the blower meets spec" to "find the operating duty-cycle
range for a motor that exceeds spec." The aftermarket Lamb-pattern vacuum
motor will have far more pressure than the system needs at 100% conduction;
the question is where to operate the TRIAC.

What to measure now that the motor is in hand:

- **Bypass-cooling confirmation (BEFORE bench testing).** Identify the cooling
  airpath and the working airpath. Run the motor briefly with a paper towel
  held over the working inlet — the working impeller stalls; the motor must
  *not* stall (cooling impeller is independent). If both stop, it's
  flow-through — reject this motor.
- **No-load draw at 120 V.** Clamp meter on one motor lead. Establishes the
  baseline for the CT-001 airflow-interlock threshold.
- **CFM vs. TRIAC conduction angle.** With the working impeller plumbed to a
  manometer + restriction plate, sweep the dimmer from minimum smooth running
  (often ~30%) to 100% in steps. Record CFM at the 2.5" and 3.0" chamber
  operating-pressure points (1.5" and 2.0" WC respectively).
- **Smooth-running floor.** Universal motors don't run cleanly at very low
  conduction — find the lowest conduction angle that still produces stable
  rotation. This sets the bottom of the operating duty-cycle range.
- **Goal:** define a TRIAC duty-cycle range that maps to the 8–18 CFM
  operating envelope across both chambers, with margin for chaff-mesh loading
  (T8) and bed-depth variation.

### Plenum pan (1/6 size steam table pan)
- Internal dimensions (L × W × H) — confirm ~6" × 6" × 4" minimum
- Wall material and thickness — should be 18/8 or 304 SS
- Rim/flange width — needed to size clamping ring bolts
- Where to drill the side-entry hole (centered on one wall, as low as practical)
- Whether rim is flat enough for gasket sealing
- M2: Assess wall thickness for stub tube installation

### Borosilicate glass tube (A3)
- Confirm 3.0" OD and wall thickness
- Check ends are fire-polished (no sharp edges)
- Handle with care — thermal shock risk during testing

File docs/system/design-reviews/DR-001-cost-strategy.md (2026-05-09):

# DR-001: Cost Strategy — Thrift and Adapt Where We Can

**Date:** 2026-04-10
**Status:** DECIDED

## Decision

This project will prioritize low-cost, resourceful sourcing for the v1 prototype.
Consumer parts, thrift store finds, salvage, and Amazon generics are preferred over
industrial catalog parts wherever they meet the functional requirement.

Engineering specs may be flexed slightly to accommodate available cheap parts —
for example, designing the heater can geometry around a salvaged hair dryer element
rather than specifying an exact element and ordering it.

## Rationale

- This is a learning platform, not a product. Every dollar saved is a dollar
  available for iteration.
- A $5 thrift store hair dryer contains both a 1500W heater element and a blower
  motor already matched for airflow — collapsing ~$80 of separate component
  sourcing into one purchase.
- Generic ESP32 boards, MAX31855 breakouts, and K-type thermocouples from Amazon
  are functionally identical to name-brand equivalents at 1/3 the price.
- Stainless steel containers, exhaust pipe, and plumbing fittings are cheaper
  than ordering tube stock from metals suppliers and often come in useful sizes.
- The prototype will be rebuilt and modified many times. Expensive precision parts
  will be wasted if the design changes.

## Where to be resourceful

| Component | Cheap source | Est. cost |
|---|---|---|
| Heater element | Harbor Freight Warrior heat gun (DR-002) | $10 |
| Blower motor | Aftermarket Lamb 116336-01-pattern bypass-cooled vacuum motor, Amazon (DR-011) | $60-90 |
| Blower control kit | TRIAC dimmer + ZMCT103C CT + line filter + ferrites (DR-011) | $15-25 |
| Chamber tube | Auto exhaust pipe (2.5"/3.0") or thrift store SS thermos | $5-15 |
| Plenum body | SS steam table pan, steel junction box, or paint can | $3-10 |
| Distributor plate | Perforated SS sheet (Amazon) cut to size, or drilled jar lid | $5-12 |
| ESP32 | Generic dev board (Amazon) | $5-7 |
| MAX31855 x3 | Generic breakouts (Amazon) | $12-18 |
| SSR | Generic 25A (Amazon) + thermal fuse backup | $6-10 |
| K-type TC x3 | SS-sheathed probes (Amazon) | $9-15 |
| 5V PSU | Old USB phone charger from junk drawer | $0 |
| Wiring + connectors | Assortment kits (Amazon) | $10-15 |
| Fuse, switch, strain reliefs | Hardware store | $5-10 |

**Estimated v1 BOM total: $50-80**

## Where NOT to cheap out

These items are either safety-critical or affect measurement quality. Buy proper parts:

- **Fuse or breaker** — real 15A rated, from a hardware or electrical store
- **Mains wiring** — 14 AWG minimum, new, rated insulation
- **Strain reliefs** — proper cord grips on every mains entry point
- **Grounding hardware** — ring terminals, star washers, proper chassis bonding
- **TC amplifier boards** — generic MAX31855 is fine, but don't skip the amplifier
  and try to read raw TC voltage on an ADC. The cold-junction compensation and
  signal conditioning matter.
- **SSR backup** — add a thermal fuse (~$1) on the heater as an independent
  last-resort cutoff in case the SSR fails shorted

## Implications for downstream design

1. **Heater can geometry** will be designed around whatever element we harvest,
   not the other way around. Get the hair dryer first, measure the element,
   then design the can.
2. **Blower characterization** happens on the bench with the actual purchased
   unit before committing to airflow numbers. The architecture doc's
   CFM estimates are targets, but real numbers come from the real part.
3. **Chamber dimensions** are set by available tube stock (2.5" and 3.0" OD
   standard sizes), which is already aligned with cheap sourcing.
4. **Plenum dimensions** will be driven by whatever container we adapt. Design
   the baffles to fit the container, not the other way around.
5. **The BOM becomes a shopping list** — some items are "go to the thrift store
   and find one" rather than "order part number X from vendor Y."

## Design-to-cost sequence

Because several dimensions depend on what parts we actually find:

1. **Source the hair dryer / heat gun first** — this determines heater element
   size, heater power, and possibly the blower
2. **Source the chamber tubes** — standard sizes, easy to get
3. **Source the plenum container** — then design baffles to fit
4. **Order electronics** — these are spec-driven, not geometry-driven
5. **Design the mechanical assembly around what we have**

This is the opposite of traditional engineering (design first, then source).
For a cheap v1 prototype, it's the right approach. We design around available
parts rather than specifying parts to match a design.

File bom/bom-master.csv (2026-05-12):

Item | Category | Description | Qty | Spec | Source | Est Cost | Status | Notes
HTR-001 | Electrical | Heater element (salvaged) | 1 | ~1500W 120V nichrome on mica former; element pack 1.5in wide x 6in long (measured 2026-05-07) | Harbor Freight Warrior heat gun SKU 56434 | $10 | In hand | Teardown completed 2026-05-07. Element pack measured 1.5in x 6in. Drives HTR-CAN-001 length to 178mm (7in) — see baseplate-layout.md §3.3. A1 rejected — element extracted and mounted in custom heater can per DR-002. Still TODO before commissioning: measure element cold resistance (target ~9.6 ohm for 1500W/120V) and photograph mounting-tab geometry for HTR-CAN-001 fabrication.
BLW-001 | Electrical | Vacuum motor (aftermarket Lamb 116336-01-pattern) | 1 | Aftermarket 2-stage 120V peripheral bypass vacuum motor (Lamb 116336-01-pattern); 5.7in motor disc OD x 2 5/8in tall + 3.5in motor body OD x ~3.75in tall; total height 6 3/8in; vent band z=1 3/8in to 2in from disc bottom (5/8in louvered ring); ø1.50in / 38.10mm axial working-air intake on disc bottom face; included Gasket 566 seats around the intake; side mount tabs at brush level | Amazon — aftermarket replacement for Lamb 116336-01 / 56207802 / 44903A B0F89ZQ23G | $60-90 | In hand | DR-011 supersedes DR-003. Aftermarket cross-reference replacement (B0F89ZQ23G) — sold as drop-in for the same OEM positions as Lamb 116336-01: Beam/NuTone/Vacuflo/AirVac central vacs; Tennant/Nilfisk A5/T5 floor scrubbers. Seller listing explicitly claims "Peripheral bypass discharge"; visible vent topology matches the genuine Ametek Product Bulletin 116336-01 (March 1998). Vent map (annotated in build/photos/blower-motor/annotated_assembled.jpg + annotated_bottom.jpg): VACUUM INTAKE = ø1.50in axial center of disc bottom face — gasket 566 seats here, working-air suction; VACUUM EXHAUST = peripheral louvered ring around disc perimeter (z=35-51mm) — working-air discharge; AIR INTAKE = top star grille — cooling-air in; cooling-air out = brush vent band at motor-to-disc transition. Speed control via BLW-CTRL-001 TRIAC dimmer; airflow interlock via CT-001; frame earth-bonded via BOND-001. Working discharge captured by BLW-HOUS-001 commercial OEM fan shell (bolt-pattern compatibility predicated on seller's drop-in claim — verify gasket/bolt-circle fit before final assembly). Mounted on rear angle-iron extension via the two side mount tabs at the brush level. Static-pressure headroom is huge (20-80in WC) — characterize at TP-001 to find operating duty-cycle range, not whether it meets spec. Link: https://www.amazon.com/dp/B0F89ZQ23G
BLW-HOUS-001 | Mechanical | Blower fan shell housing (commercial OEM) | 1 | Ametek Lamb 45899-14 epoxy-coated steel fan shell with integrated 1.5in OD pipe tube outlet; OEM bolt-on for 5.7in Lamb/Ametek peripheral-bypass motors; ~1.2 lb | Amazon — Ametek Lamb 45899-14 B07YXCMCXC (alt B07H2LK6LS); The Vacuum Factory MTR1802 as cheaper non-Amazon alternative | $47-50 (Amazon) / $34.95 (Vac Factory) | Needs sourcing | DR-014 (2026-05-09) + DR-015 (2026-05-09): commercial OEM housing replaces fabricated stovepipe collector. Bolts onto BLW-001 disc face via 4× ø0.150in holes on ø4.625in BC (per Ametek 116336-01 datasheet — verify on the actual aftermarket unit before ordering). Outlet is AXIAL (off-center on the dome face, parallel to the motor shaft), 1.5in OD pipe tube — confirmed via Ace Vacuums product photo 2026-05-09. With BLW-001 mounted shaft-vertical, the housing outlet points vertically; BLW-ELBOW-001 turns the discharge horizontal forward to mate with BLW-COUP-001 reducer into the heater can. Same housing PN used inside central vacuum power units (Beam/NuTone/Vacuflo/AirVac). The motor's included Gasket 566 is for the motor-to-bulkhead seal; the housing-to-motor seal needs its own gasket — see BLW-HOUS-GSK-001. Order alongside BLW-HOUS-GSK-001 + BLW-ELBOW-001 + BLW-COUP-001. Amazon link: https://www.amazon.com/dp/B07YXCMCXC ; Vac Factory alternate: https://www.thevacuumfactory.com/product/5-7-lamb-ametek-fan-shell-cover-with-1-5-pipe-tube/
BLW-HOUS-GSK-001 | Mechanical | Fan-shell-to-motor gasket | 1 | 5.7in OD rubber gasket — Fitall Lamb Ametek Motor Gasket 5.7in #566 | Amazon — Fitall Lamb Ametek Motor Gasket 5.7'' #566 B01N4W4T3V | $5-8 | Needs sourcing | DR-015 (2026-05-09): the 45899-14 fan shell is sold without a gasket ("mounting bolts and gasket must be purchased separately" per Ace Vacuums listing). The motor includes a Gasket 566 from the factory; whether that one doubles as the housing-to-disc seal or is reserved for a different OEM-application interface is not clearly documented in primary sources. Order this Fitall #566 as either the shell gasket or a spare — at $5–8 it's cheap insurance to have one on the bench at assembly. Link: https://www.amazon.com/dp/B01N4W4T3V
BLW-ELBOW-001 | Mechanical | Blower outlet 90-degree elbow | 1 | Silicone 90-degree elbow hose 1.5in / 38mm ID; 4in / 102mm legs; 4-ply reinforced; black; ~5mm wall | Amazon — Haturmyko 1.5in ID 90-degree silicone elbow coupler B0FM32NMQ4 | $10-15 | Needs sourcing | DR-015 (2026-05-09): redirects BLW-HOUS-001's axial outlet from vertical (motor-shaft-parallel) to horizontal forward at heater-can centerline elevation. Without this, a vertical-axis motor mount + axial housing outlet would aim discharge straight up. Selected over rotating BLW-001 to shaft-horizontal because vertical-axis keeps the cooling-air intake (top star grille) facing up and away from the air train. Silicone also adds vibration isolation. Automotive turbo-intake silicone (~250C / 482F rating) is far above this leg of the air train (post-blower, pre-heater = near-ambient). Worm-drive hose clamps both ends (covered by EXH-003). 4in legs give working room for clamps at both joints. Order alongside BLW-COUP-001. Link: https://www.amazon.com/dp/B0FM32NMQ4
BLW-COUP-001 | Mechanical | Blower-to-heater-can coupler | 1 | Silicone straight reducer hose 1.5in / 38mm to 2.5in / 63mm ID; 3in / 76mm long; 4-ply reinforced; black | Amazon — AotoKoop 1.5in to 2.5in straight silicone reducer coupler B094HSP16W | $10-14 | Needs sourcing | DR-014 (2026-05-09): bridges BLW-ELBOW-001's 1.5in horizontal output (itself fed from BLW-HOUS-001's axial outlet) to the 2.5in heater can inlet (HTR-CAN-001). Worm-drive hose clamps both ends (covered by EXH-003). Silicone also provides vibration isolation between motor and rigid heater-can/plenum stack. Automotive turbo-intake silicone (~250C / 482F rating) is far above this leg of the air train (post-blower, pre-heater = near-ambient). Link: https://www.amazon.com/dp/B094HSP16W
BLW-CTRL-001 | Electrical | TRIAC dimmer module (blower speed control) | 1 | AC light dimmer module 8A with on-board zero-cross detector; logic-level PWM input + ZC output (RobotDyn-style) | Amazon — Genuine RobotDYN PWM AC dimmer 110-220V w/ heatsink B071X19VL1 | $10-15 | Sourced | DR-011: ESP32 GPIO 23 → PWM in (gate trigger); GPIO 4 ← ZC out (interrupt). Genuine RobotDYN 1-channel module — 3.3V/5V logic, 50/60Hz, includes heatsink. BTA16-class TRIAC; rated for ~8A continuous on inductive loads. Drive with RBDdimmer.h or roll-your-own ZC ISR + phase-angle scheduler. 4-channel alt B07NDW2F3F if multi-zone control ever needed. Link: https://www.amazon.com/dp/B071X19VL1
CT-001 | Electrical | Current transformer (airflow interlock) | 1 | ZMCT103C 5A split-core CT module with burden + bias network | Amazon — HiLetgo 3pcs ZMCT103C 5A AC current sensor w/ op-amp B0CDWWYLMQ | $8-10 (3-pack) | Sourced | DR-011: replaces implicit blower_is_running() check from DR-003. Clamp on one motor lead. Output AC riding mid-rail to ESP32 GPIO 34 ADC; firmware computes RMS for airflow interlock threshold. HiLetgo board has onboard precision op-amp + biasing — output is voltage (not raw 5mA secondary), directly ADC-readable. 3-pack gives 2 spares. 1000:1 ratio, 0.2% linearity, 3000V isolation. Link: https://www.amazon.com/dp/B0CDWWYLMQ
FILT-001 | Electrical | AC line filter | 1 | X-cap line-to-neutral + Y-caps to earth; 6-10A inline module | Amazon — uxcell CW4L2-10A-T 115/250V 10A EMI filter B016EISSGE | $8-12 | Sourced | DR-011: contains conducted EMI from TRIAC switching + brushed-motor commutation. Mandatory for SPI signal integrity. CW4L2-10A-T is a chassis-mount terminal-block filter (common-mode choke + X+Y caps); install inline on motor leads between fuse bus and BLW-CTRL-001. Earth lug on case must bond to chassis ground. Salvage from a dead PC PSU input stage is a no-cost alternative if available. Link: https://www.amazon.com/dp/B016EISSGE
FERR-001 | Electrical | Snap-on ferrite chokes | 1 lot | Mixed-bore clamp-on ferrite cores (4mm-10mm cable diameters); set of 5-10 | Amazon — IEUYO 22-pc clip-on ferrite kit 5 sizes 3/5/7/9/13mm B07DPM44BV | $8-10 | Sourced | DR-011: install on motor leads (between TRIAC and motor) and on every TC SPI cable run. Brushed motor + TRIAC switching is a significant EMI source — E13 shielded cable is necessary but not sufficient on its own. 22-pc kit covers 3-13mm cable diameters — fits TC SPI cables (small) and motor leads (larger). Snap-on, no soldering. Plenty of spares. 70-pc alt B0CP5Q2KLP if more inventory needed. Link: https://www.amazon.com/dp/B07DPM44BV
BOND-001 | Electrical | Motor frame earth bonding lug | 1 | M4 or #8 ring terminal + matching screw / star washer; green/yellow stranded pigtail 14 AWG | Hardware store | $1 | Needs sourcing | DR-011: universal motors have nontrivial leakage current — frame must be bonded to mains earth. Ring terminal under a frame screw with a star washer for positive metal-to-metal contact
SSR-001 | Electrical | Zero-cross solid state relay | 1 | 25A 120V AC load / 3-5V DC control | Amazon — SSR-25DA generic B07FVR37QN | $5-8 | Sourced | Drive via NPN buffer from 5V rail (E7); add RC snubber across output (E10); add thermal fuse as independent backup. 3-32V DC input / 24-380V AC out. Link: https://www.amazon.com/dp/B07FVR37QN
ESP-001 | Electrical | ESP32 dev board | 1 | ESP32-DevKitC clone | Amazon — HiLetgo ESP-WROOM-32 B0718T232Z | $5-7 | Sourced | Hardware WDT enabled in firmware (E1/F2). Single-board listing; 2-pack alt B09KLQF4RR. Link: https://www.amazon.com/dp/B0718T232Z
TC-AMP-001 | Electrical | MAX31855 TC amplifier breakout | 3 | SPI K-type | Amazon — NOYITO MAX31855 B07K5MJ43M (qty 3) | $4-6 ea | Sourced | Total ~$12-18; use shielded cable to reduce SPI noise near SSR switching (E13). Order 3 individual units (cheaper than 3-packs). Alt: HUABAN B083R5F3FF. Link: https://www.amazon.com/dp/B07K5MJ43M
TC-001 | Sensor | K-type thermocouple - process air (TC1) | 1 | SS sheath probe K-type 3mm OD | Amazon — Industrial Q-K-01 B078QS3NWP | $3-5 | Sourced | Post-heater pre-plenum placement; compression fitting mount (M9). 6in long 0.118in (3mm) 316SS sheath quick-disconnect K-type up to 500C. Order qty 3 of this listing for TC-001/002/003. Link: https://www.amazon.com/dp/B078QS3NWP
TC-002 | Sensor | K-type thermocouple - bean bed (TC2) | 1 | SS sheath probe K-type 3mm OD | Amazon — Industrial Q-K-01 B078QS3NWP | $3-5 | Sourced | Side-entry lower chamber; compression fitting mount (M9). Same listing as TC-001. Link: https://www.amazon.com/dp/B078QS3NWP
TC-003 | Sensor | K-type thermocouple - exhaust (TC3) | 1 | SS sheath probe K-type 3mm OD | Amazon — Industrial Q-K-01 B078QS3NWP | $3-5 | Sourced | Exhaust stream above chamber; compression fitting mount (M9). Same listing as TC-001. Link: https://www.amazon.com/dp/B078QS3NWP
TC-FIT-001 | Sensor | TC compression fittings | 3 | 1/8in compression fitting 1/8 NPT to 1/8 OD | Amazon — Pysrych B09FF7LRL6 (2-pack qty 2) | $3-5 ea | Sourced | Positive sealing and strain relief for TC probes (M9). Pack of 2 — order 2 packs for 4 fittings (3 needed + 1 spare). 304 SS double-ferrule. Link: https://www.amazon.com/dp/B09FF7LRL6
PSU-001 | Electrical | 5V power supply | 1 | 5V 2A USB charger | Junk drawer | $0 | Thrift hunt | Old phone charger; must be isolated (all modern ones are)
FUSE-001 | Electrical | Fuse or breaker | 1 | 20A 120V inline (was 15A — DR-013 D4) | Hardware store | $2-3 | Needs sourcing | DR-013 D4: bumped to 20A. Heater 12.5A + universal-AC motor 1-4A = 13.5-17A peak; 15A breaker trips at the high end and exceeds NEC 80% continuous (12A) at any motor load. Pair with 12 AWG WIRE-001 and PLUG-001 (NEMA 5-20). Required circuit is a 20A branch — see PLUG-001 notes for safety-label text.
SW-001 | Electrical | Hard disconnect switch | 1 | 120V 15A DPST toggle or rocker | Hardware store | $3-5 | Needs sourcing | E8: Must be double-pole (switches both L and N) to protect against reversed cord polarity. Must be accessible during operation
SW-002 | Electrical | Heater Enable switch (panel) | 1 | SPST toggle panel-mount; low-voltage rating sufficient (carries ~5V / ~10mA SSR control signal only — NOT mains) | Amazon — any panel-mount SPST toggle | $2-5 | Needs sourcing | DR-016 D1: wired in series with ESP32 -> SSR control line. ESP32 also reads switch state via a digital input pin so firmware refuses to assert heater duty when disabled. Defense-in-depth on SSR control: cuts heater without disturbing blower, independent of firmware state. Mount on front panel next to LED-001/002. Lighted is fine but unnecessary — FAULT LED covers the visual side.
LED-001 | Electrical | POWER indicator LED (panel) | 1 | 5mm or 10mm panel-mount LED green; pre-wired with bezel preferred | Amazon — generic panel-mount LED indicator | $1-3 | Needs sourcing | DR-016 D2: lights when mains is energized downstream of SW-001 disconnect. Drive from ESP32 GPIO or directly from 5V via current-limit resistor (~330R from R3-001 kit). At-a-glance "mains is hot" indicator near the front panel.
LED-002 | Electrical | FAULT indicator LED (panel) | 1 | 5mm or 10mm panel-mount LED red; pre-wired with bezel preferred | Amazon — generic panel-mount LED indicator | $1-3 | Needs sourcing | DR-016 D2: latched fault indicator from safety layer (over-temp / airflow loss / TC failure / USB watchdog / etc.). Driven by ESP32 GPIO through current-limit resistor (~330R from R3-001 kit). Stays lit until fault state is cleared by operator reset.
UI-001 | UI/Host | Raspberry Pi 5 8GB | 1 | Raspberry Pi 5 single-board computer with 8GB RAM; ARM Cortex-A76 quad-core; 2x micro-HDMI; 4x USB (2x USB 3.0 + 2x USB 2.0); WiFi 6 / BT 5.0 | Amazon — official Pi 5 8GB | $80 | Needs sourcing | DR-017: Artisan host. Mounts in new Zone E (front of baseplate). USB-tethered to ESP32 (Variant A transport). Pi 5's WiFi enables Artisan WebLCDs for iPad-on-LAN secondary view.
UI-002 | UI/Host | Pi 5 official 27W USB-C PSU | 1 | Official Raspberry Pi 27W USB-C power supply 5V/5A; white or black | Amazon — official Pi 5 27W PSU | $12 | Needs sourcing | DR-017: Pi 5 requires this PSU spec — undervolts on weaker (Pi 4 era 15W) supplies. Powers Pi + display via Pi USB rail. Display USB draw must fit in 1.6A USB budget — see verification gate G2.
UI-003 | UI/Host | Pi 5 active cooler | 1 | Official Pi 5 active cooler (heatsink + fan) or equivalent low-profile clone | Amazon — official Pi 5 active cooler | $5 | Needs sourcing | DR-017: Pi 5 throttles fast without active cooling under sustained load. Fullscreen Artisan + USB serial is light load but enclosure ambient (Zone E) may exceed 30C — keep margin.
UI-004 | UI/Host | microSD boot card | 1 | microSD 64GB A2 V30 (SanDisk Extreme or Samsung Pro Plus class) | Amazon — SanDisk Extreme 64GB or equivalent | $10 | Needs sourcing | DR-017: boot drive for Raspberry Pi OS 64-bit. A2 / V30 ratings give the random-IO performance Pi 5 expects. 64GB is plenty for OS + Artisan + roast logs.
UI-005 | UI/Host | micro-HDMI to HDMI cable | 1 | Micro-HDMI (Type D) male to HDMI (Type A) male; ~12 in / 30 cm; gold-plated | Amazon — generic short micro-HDMI cable | $5 | Needs sourcing | DR-017: Pi 5 has 2x micro-HDMI outputs; on-hand display uses full-size HDMI. Short cable for Zone E integrated mount. Verify display HDMI input is Type A standard before locking (G1).
UI-006 | UI/Host | Pi to ESP32 USB cable | 1 | USB-A male to ESP32 connector (typically micro-B or USB-C); short ~12-18 in; with snap-on ferrite from FERR-001 | Amazon — short USB cable matching ESP32 dev board connector | $3-5 | Needs sourcing | DR-017: USB serial tether between Pi 5 and ESP32 (Variant A transport). Short cable + ferrite from FERR-001 to manage EMI between TRIAC switching and USB signal. Positive-latch USB-C preferred over micro-B if ESP32 breakout supports it (per DR-016 USB-drop mitigation).
UI-007 | UI/Host | Zone E mounting hardware | 1 lot | Standoffs / brackets / fasteners for Pi 5 + display mount; M2.5 standoffs for Pi PCB; M3 for display brackets; bracket fab from BASE-001 angle iron offcut | Hardware store + BASE-001 offcuts | $5-10 | Needs sourcing | DR-017: integrated mount of Pi 5 + 7in display to Zone E (front of baseplate). Geometry deferred until G3 (mockup fit check). Likely vertical orientation facing operator; thermal baffle between Zone B/C and Zone E to keep Pi enclosure ambient below 50C.
THFUSE-001 | Electrical | Thermal fuse - heater can body | 1 | 228C one-shot (240C accepted) | Amazon — NEC SF240E B015675DA8 | $1-2 | Sourced | Mounts on heater can body; independent last-resort cutoff if SSR fails shorted. NEC SEFUSE 240C 10A axial — 228C unavailable from major sellers in singles. 240C is 12C above target but well below nichrome failure; acceptable per safety-critical substitution review. Link: https://www.amazon.com/dp/B015675DA8
THFUSE-002 | Electrical | Thermal fuse - airstream | 1 | 192C one-shot | Amazon — BF192 B0FJ5WJM9Z (10-pack) | $1-2 | Sourced | E6: Mounts in heated airstream downstream of element. Lower rating than THFUSE-001 and lower thermal lag — trips faster on no-airflow overheat. AUPO BF192 10A axial. 10-pack — keep spares for replacements after trips. Link: https://www.amazon.com/dp/B0FJ5WJM9Z
Q2-001 | Electrical | NPN transistor (SSR buffer) | 1 | 2N2222 or similar TO-92 | Amazon — OCR transistor kit B071KK9B3H | $0-1 | Sourced | E7: Buffers ESP32 3.3V GPIO to 5V for reliable SSR triggering. Kit covers 2N2222 and many other useful TO-92 BJTs. Link: https://www.amazon.com/dp/B071KK9B3H
R3-001 | Electrical | SSR buffer base resistor | 1 | 1k ohm 1/4W axial | Amazon — ELEGOO 525pc resistor kit B072BL2VX1 | $0-1 | Sourced | E7: Limits base current for Q2 NPN buffer. ELEGOO 17-value 1% kit covers a wide range — keep on hand for incidental needs. Link: https://www.amazon.com/dp/B072BL2VX1
R-SNB-001 | Electrical | Snubber resistor | 1 | 47 ohm 2W | Amazon — uxcell 60-pack B07V2NV3P9 | $0-1 | Sourced | E10: RC snubber across SSR output — suppresses inductive spikes. Metal oxide flame-proof axial 5%. Link: https://www.amazon.com/dp/B07V2NV3P9
C-SNB-001 | Electrical | Snubber capacitor | 1 | 0.01uF 275VAC X2-rated film cap | Amazon — X2 275VAC 10nF B09JWZ5MWQ | $1-2 | Sourced | E10: RC snubber across SSR output — must be X2-rated for mains use. 275VAC X2 = equivalent safety class to 400VDC for mains snubber duty. 103K 10mm pitch. Link: https://www.amazon.com/dp/B09JWZ5MWQ
CHAM-001A | Mechanical | Roast chamber - primary (SS) | 1 | 2.5 in OD 304 SS exhaust pipe 12 in length | In hand 2026-05-09 — existing 24in 2.5in OD SS exhaust pipe stock | $0 | In hand | Cut plan from 24in 2.5in stock: 12in CHAM-001A + 7in HTR-CAN-001 + ~2in PLEN-005 stub tube (~3in scrap). Standard exhaust size; ~2.37 in ID. T3: L/D ~1.0 — slugging risk; 3.0in may be preferred.
CHAM-001B | Mechanical | Roast chamber - backup (SS) | 1 | 3.0 in OD 304 SS exhaust pipe 12 in length | In hand 2026-05-09 — existing 24in 3.0in OD SS exhaust pipe stock | $0 | In hand | Cut plan from 24in 3.0in stock: 12in CHAM-001B + ~12in scrap retained for EXH-004 cone reducer fab and future use. Standard exhaust size; ~2.87 in ID. T3: L/D ~0.57 — better fluidization geometry.
CHAM-001C | Mechanical | Roast chamber - glass option | 1 | 3.0 in OD borosilicate glass cylinder ~8 in (down from 10-12 in target) | Amazon — SUNWO B06XJT46QL | $5-10 | Sourced | A3: Visual feedback on fluidization and roast development. Borosilicate 3in dia x 8in tall open-end chimney/lampshade. NOTE: 8in is shorter than original 10-12in target — verify expansion-chamber transition still clears bean bed. Handle with care — thermal shock risk. Test alongside SS tubes. 2-pack alt B075ZQFFK4. Link: https://www.amazon.com/dp/B06XJT46QL
PLEN-001 | Mechanical | Plenum body | 1 | 8in dia x 6in tall black stovepipe section + 3 slip-fit pipe caps (1 bottom + 2 swappable tops drilled to 2.5in and 3.0in chamber OD respectively) | Sourced 2026-05-04 — 2ft black pipe + 3 caps in hand | $0 | Sourced | DR-012 + DR-013 D3: 3 caps map to 1 permanent bottom + 2 swappable tops (one per chamber size) for the DR-001 dual-chamber test. PRE-USE GATES (DR-013): (1) verify pipe is bare/oxide-blackened mild steel — NOT galvanized HVAC duct. Zinc outgases at exactly our 200C operating temp. Galvanized = stop and re-source. (2) M7 cure-burn outdoors with propane torch until rolling-oil film stops smoking, before any food-path roasting. (3) Do NOT drill the 2.5in side-entry hole-saw until HTR-001 teardown is complete and HTR-CAN-001 outlet geometry is known — side-entry position depends on heater can length. Top caps: drill one to 2.5in chamber OD, one to 3.0in. Each is the clamp-ring substrate for its chamber size (DR-008). Bottom cap retained with 3 sheet-metal screws + high-temp RTV at the seam.
PLEN-002 | Mechanical | Clamping ring - 2.5in chamber | 1 | 2in automotive exhaust flange (mild or stainless steel); ID ~2.0in OD ~3.5-4in; drill 3 fresh M4 tap holes in face. Fallback: 1/8in SS plate annular ring cut to OD ~4in ID 2.0in | Auto parts store (AutoZone/O'Reilly) — pick up alongside CHAM-001A/B exhaust pipe stock; SS plate offcut as fallback | $5-15 (flange) / $0-3 (fab fallback) | Needs sourcing | DR-008 + 2026-05-02 geometry correction (Option A). Ring ID 2.0in < chamber ID 2.37in so ring's inner face supports PLATE-001A (dia 2.37in) from below — plate drops inside chamber and rests on ring face. Chamber 2.5in OD passes through 2.5in cap hole; bottom rim sits on same ring face around the plate edge. 2in exhaust flange ID matches our target directly and is heat-rated for continuous exhaust use (massively over-spec at 200C). Factory bolt holes are oversized clearance (3/8in or 7/16in) — not M4-tappable; drill 3 fresh M4 tap holes elsewhere on the flange face. Tapped ring (M4 screws from above through cap face) preserves DR-008 ring+plate swap without breaking DR-012 bottom-cap RTV seal. 2-bolt flanges are most common; 3-bolt OK if available. Mild steel flange is fine for our temps; stainless is optional/cosmetic. M3: fender washers under cap-side screw heads
PLEN-003 | Mechanical | Clamping ring - 3.0in chamber | 1 | 2.5in automotive exhaust flange (mild or stainless steel); ID ~2.5in OD ~4-4.5in; drill 3 fresh M4 tap holes in face. Fallback: 1/8in SS plate annular ring cut to OD ~4.5in ID 2.5in | Auto parts store — same trip as PLEN-002 + CHAM-001A/B; SS plate offcut as fallback | $5-15 (flange) / $0 (fab fallback from PLEN-002 stock) | Needs sourcing | DR-008 + 2026-05-02 geometry correction (Option A). Ring ID 2.5in < chamber ID 2.87in; supports PLATE-001B (dia 2.87in) from below. Same exhaust-flange rationale as PLEN-002 — 2.5in flange ID matches our target ring ID directly. Drill 3 fresh M4 tap holes; ignore factory clearance holes. Swap pair with PLATE-001B for 3.0in chamber. Each chamber size also requires its own top cap (drilled to chamber OD); cap is part of the swap unit. M3: fender washers under cap-side screw heads
PLEN-004 | Mechanical | Plenum gasket | 1 | Fiberglass stove rope 1in dia | Amazon — Woodstove gasket rope B01ETURR0M (7ft) | $3-5 | Sourced | M8: Changed from ceramic fiber to fiberglass — ceramic fiber sheds respirable particles. High-temp seal between clamping ring and underside of top pipe cap face (DR-008 + DR-012). 7ft is more than needed; 9ft alt B01ETVGA22 / 20ft alt B01ETVSP5W. Link: https://www.amazon.com/dp/B01ETURR0M
PLEN-005 | Mechanical | Plenum side-entry stub tube | 1 | 2.5in OD SS tube stub ~2in long | Stock in hand — offcut from 24in 2.5in CHAM-001A stock | $0 | Needs fabrication | M2: Welded or press-fit through pan wall hole. Prevents pan wall deformation under hose clamp load. Use hose clamps inside + outside. Sized to match 2.5in chamber-side hose-clamp joint.
PLATE-001A | Mechanical | Distributor plate - 2.5 in | 1 | Perforated SS sheet 4in dia disc with 1/16in holes (cut to ~2.37 in) | Amazon — FengYoo 4in round B09SF15S47 | $5-8 | Sourced | DR-013 D1: run as-is at 22% open area. 4in 19-gauge 304 SS round disc with 1/16in holes. Cut to 2.37in for CHAM-001A. 22% open is well above the conventional fluid-bed sweet spot but is now characterizable via PRESS-001 dP measurement. If TP-001 stage 1 measures plate dP too low or shows channeling: install MESH-001 disc on top (Plan B). DIY-drilled custom plate at 4% open area held as Plan C. DR-013 D2 plate-float check: at 22% open, actual operating plate dP is far below 1in WC, so plate weight (~23g) is comfortably above actual lift force (~5gf). Link: https://www.amazon.com/dp/B09SF15S47
PLATE-001B | Mechanical | Distributor plate - 3.0 in | 1 | Perforated SS sheet 4in dia disc with 1/16in holes (cut to ~2.87 in) | Amazon — FengYoo 4in round B09SF15S47 | $5-8 | Sourced | DR-013 D1: same handling as PLATE-001A. Cut to 2.87in for CHAM-001B. Order 2 of the FengYoo listing total to cover both chamber sizes. MESH-001 disc cut to 2.87in is the staged Plan B. Link: https://www.amazon.com/dp/B09SF15S47
BAFFLE-001 | Mechanical | Deflector ramp baffle | 1 | SS sheet ~3x4in bent to 45deg | Salvage or hardware store | $0-3 | Needs fabrication | Pop-riveted to inside of cylindrical plenum wall opposite side-entry; redirects jet to plenum floor (DR-009 + DR-012). Curved wall vs flat — ramp seats on a chord; small edge standoff is immaterial. T2: If TP-001 shows uneven fluidization add second perforated baffle ~1in below distributor plate (6in plenum height has explicit headroom)
EXH-001 | Mechanical | Chaff expansion chamber | 1 | ~4in OD x 5in tall SS cylinder or can | Thrift store / restaurant supply (no good Amazon match) | $3-10 | Needs sourcing | Step-up from chamber OD; chaff settles by velocity drop (DR-006). Look for SS flatware caddy / utensil cylinder / coffee tin / SS cup at thrift. No clean Amazon listing matches 4in dia x 5in tall in pure SS at low cost — defer to thrift hunt
EXH-002 | Mechanical | Chaff mesh screen | 1 | 30 mesh 304 SS woven sheet ~4in dia disc cut | Amazon — 30 mesh 304 SS B09VNSQGVH (11.8x23.6in) | $3-5 | Sourced | Cut from sheet; fits inside top of expansion chamber (DR-006). T8: May clog with chaff oils — plan for mid-roast cleaning or test coarser mesh. Sheet is large — plenty for spares. Link: https://www.amazon.com/dp/B09VNSQGVH
EXH-003 | Mechanical | Hose clamps - all-stainless | 4-6 | All-stainless worm-drive clamp sized to joints | Hardware store | $1-2 ea | Needs sourcing | M11: Must be all-stainless (not zinc-plated) for temperature tolerance. Covers blower-to-can heater-can-to-plenum and expansion chamber joints
EXH-004 | Mechanical | Cone reducer - expansion chamber | 1 | Sheet metal cone from chamber OD to ~4in expansion chamber OD | Fabricate from SS sheet | $0-3 | Needs fabrication | M6: Transition from roast chamber to expansion chamber. Hose clamp at each end
CHAM-RET-001 | Mechanical | Chamber tube retention hardware | 1 | 3 set screws or spring clips | Hardware store | $2-3 | Needs sourcing | M4: Chamber tube must not be held by gravity alone — vibration or bump will tip it. Set screws through clamping ring or spring clips
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

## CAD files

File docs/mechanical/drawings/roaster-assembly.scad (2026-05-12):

// =============================================================
// Fluid-Bed Coffee Roaster v1 — Assembly Model
// =============================================================
// Parametric model for visualization and fit-checking.
// All dimensions in millimeters. Render with OpenSCAD.
//
// Usage:
//   - Open in OpenSCAD and press F5 (preview) or F6 (render)
//   - Toggle components on/off with show_* variables below
//   - Switch chamber size with chamber_od variable
//
// Reference: docs/system/architecture.md, docs/mechanical/baseplate-layout.md,
// docs/system/design-log.md (DR-008, DR-009, DR-011, DR-012, DR-013).
//
// Geometry as of 2026-05-07: motor + heater element measured and in hand;
// 12" × 18" steel deck cut from BASE-001 stock; angle-iron frame with rear
// (motor) and front (electronics) extensions.
// =============================================================

// --- Configuration -------------------------------------------

// Chamber selection: 63.5 (2.5" OD) or 76.2 (3.0" OD)
chamber_od = 63.5;  // mm — change to 76.2 for backup chamber

// Component visibility toggles
show_deck            = true;
show_frame           = true;
show_extensions      = true;
show_legs            = true;       // DR-013 tripod legs
show_plenum          = true;
show_top_cap         = true;
show_bottom_cap      = true;
show_clamp_ring      = true;
show_distributor     = true;
show_baffle          = true;
show_chamber         = true;
show_cone_reducer    = true;
show_chaff_collector = true;
show_heater_can      = true;
show_blower          = true;
show_electronics_box = true;
show_heat_barrier    = true;
show_zone_e          = true;       // DR-017 Pi 5 + display riser

// --- Origin convention --------------------------------------
// (0, 0, 0) is the rear-left corner of the steel deck, at the deck top
// surface. +X is to the operator's right (across the long edge);
// +Y is forward (toward the operator); +Z is up.

// --- Deck (BASE-001 cut) ------------------------------------

deck_width   = 305;     // 12 inches (X)
deck_length  = 457;     // 18 inches (Y)
deck_thick   = 1.6;     // ~16 ga steel sheet (visual only)

// --- Frame and extensions (angle iron) ----------------------

frame_angle_h    = 25.4;    // 1" angle iron
frame_angle_t    = 3.2;     // ~1/8" leg
rear_ext_length  = 152;     // 6" rear extension for motor (Zone A)
front_ext_length = 125;     // 5" front extension for electronics (Zone D)

// --- Tripod legs (DR-013) -----------------------------------

leg_rod_dia      = 9.5;     // 3/8" threaded rod
leg_below        = 100;     // exposed length below deck (adjustable feet)
leg_above        = 380;     // length above deck up to chamber-band clamp

// Leg X/Y positions: front pair straddles the plenum on the deck, rear leg
// sits on the rear extension behind the motor (forming a triangle).
front_leg_y      = 380;
rear_leg_y       = -120;
leg_x_offset     = 110;     // distance from deck centerline (X = 152.5)
deck_cx          = deck_width / 2;

// --- Plenum body (DR-012) -----------------------------------

plenum_dia       = 203;     // 8" round black stovepipe
plenum_height    = 152;     // 6" tall
plenum_wall      = 0.5;     // ~26 ga
cap_skirt        = 12;      // pipe-cap skirt depth
cap_thick        = 1.0;     // cap face thickness
plenum_y         = 329;     // CL on long axis (deck Y, see baseplate-layout.md §1)
standoff_h       = 25.4;    // 1" standoff between deck and plenum bottom cap
plenum_bot_z     = standoff_h;
plenum_top_z     = plenum_bot_z + plenum_height;

// Side-entry hole on the rear face (-Y side of the cylindrical wall),
// centerline ~2" above plenum floor (DR-009 ramp clearance).
side_entry_dia   = 64;      // 2.5" — heater-can OD
side_entry_z     = plenum_bot_z + 50;   // 50 mm above plenum floor
side_entry_y     = plenum_y - plenum_dia/2;

// --- Heater can (HTR-CAN-001, DR-002 + 2026-05-07 measurement) ---

heater_can_od    = 64;      // 2.5" SS exhaust pipe
heater_can_id    = 60;      // ~2.37"
heater_can_len   = 178;     // 7" — fits 1.5" × 6" Warrior element + ~0.5" each end

// Heater can axis sits at the same elevation as the plenum side-entry
// centerline. Heater can extends from ~Y=25 to Y=203 (measured along deck Y).
heater_y_rear    = 25;
heater_y_front   = heater_y_rear + heater_can_len;   // = 203
heater_z         = side_entry_z;

// --- Blower (BLW-001 — measured 2026-05-07) -----------------

blower_dia       = 152;     // 6" body
blower_height    = 152;     // 6" tall
blower_outlet_dia = 38;     // 1.5" / 38.10mm pipe — BLW-HOUS-001 fan shell outlet is AXIAL
                            // (off-center on dome face, parallel to motor shaft); BLW-ELBOW-001
                            // 90° silicone elbow redirects horizontal-forward to BLW-COUP-001
blower_y         = -75;     // CL ~75 mm rear of deck rear edge (on rear extension)
blower_x         = deck_cx;
blower_bot_z     = 0;       // sits on rear extension (same Z as deck top)
blower_top_z     = blower_bot_z + blower_height;
blower_outlet_z  = heater_z;   // outlet at heater-can axis elevation

// --- Clamping ring (DR-008 Option A) ------------------------

ring_outer       = chamber_od + 60;     // ~4" exhaust flange OD
ring_inner       = (chamber_od == 63.5) ? 50.8 : 63.5;  // 2" / 2.5" ID
ring_thick       = 3;

// --- Distributor plate (DR-013 D1: FengYoo plate as-is) -----

plate_dia        = chamber_od - 3.2;    // chamber ID
plate_thick      = 1.06;                // 19 ga FengYoo

// --- Roast chamber ------------------------------------------

chamber_id       = chamber_od - 3.2;
chamber_length   = 304.8;   // 12"

// --- Cone reducer (EXH-004) and chaff collector (DR-006) ----

cone_height      = 50;
chaff_od         = 101.6;   // 4"
chaff_height     = 127;     // 5"

// --- Heat barrier (between Zones C and D) -------------------

barrier_thick    = 1.5;
barrier_height   = 200;
barrier_y        = deck_length - 12;   // bolted just inside front edge

// --- Electronics tray (Zone D) ------------------------------

ebox_w           = 280;
ebox_d           = 100;
ebox_h           = 90;
ebox_y           = deck_length + 12;   // on front extension, ~12 mm past barrier

// --- Zone E: Pi 5 host + 5x7" HDMI display riser (DR-017) ---

// Display: on-hand 5x7" HDMI touch panel (HDMI in + USB power/touch in).
// Exact perimeter unmeasured (G3) — placeholder dimensions match the
// active area (5" x 7") plus an estimated 0.5" bezel each side.
display_w        = 178;     // 7" wide (X)
display_h        = 152;     // 5" tall (Z, when standing)
display_thick    = 12;      // ~12 mm panel + bezel depth
display_bezel    = 13;      // 0.5" bezel allowance on every edge (already included in w/h)

// Pi 5 PCB mounts on standoffs behind the display. M2.5 standoff stack
// raises the Pi ~12 mm clear of the back of the display for cooling
// clearance over the active cooler intake.
pi5_w            = 85;
pi5_d            = 56;
pi5_h            = 18;      // Pi 5 board + active cooler stack
pi5_standoff     = 12;

// Riser geometry: vertical stalk from the front extension. Display
// centerline targets ~1100 mm above floor (operator eye-level when
// standing), which with the DR-013 leg height puts the display centerline
// roughly leg_above - 20 mm above the deck top.
zone_e_stalk_w   = 20;      // 3/4" angle-iron / flat-bar stalk visualization
zone_e_stalk_t   = 6;       // stalk thickness
zone_e_stalk_h   = 320;     // height above deck top to display bottom edge
zone_e_tilt      = 18;      // backward tilt of display, degrees

// Position: stalk roots at the front edge of the front extension,
// centered across X.
zone_e_y         = deck_length + front_ext_length - 15;   // 15 mm back from front extension edge
zone_e_x_center  = deck_cx;

// --- Deflector ramp baffle (DR-009) -------------------------

baffle_w         = 76;
baffle_h         = 100;
baffle_t         = 1.2;
baffle_angle     = 45;

// =============================================================
// Modules
// =============================================================

module deck() {
    color("Gainsboro")
    translate([0, 0, -deck_thick])
        cube([deck_width, deck_length, deck_thick]);
}

module angle_iron(length) {
    // Angle iron section running along Y, leg up + leg out
    color("DimGray")
    union() {
        cube([frame_angle_h, length, frame_angle_t]);
        cube([frame_angle_t, length, frame_angle_h]);
    }
}

module frame() {
    // Two long-edge angles running the full assembly length (deck +
    // extensions). Cross-members at deck rear and front edges and at the
    // outer ends of the extensions.
    total_y_start = -rear_ext_length;
    total_y_len   = rear_ext_length + deck_length + front_ext_length;
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

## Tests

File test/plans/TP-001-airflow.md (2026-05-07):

# TP-001: Airflow Uniformity and Fluidization Test

## Purpose

Quantify the plenum / baffle / distributor-plate behavior and verify that the
air system can fluidize a 113 g charge of green coffee. Produce data — plate
dP curve, exhaust CFM curve, fluidization onset, entrainment velocity — that
informs distributor plate iteration (mesh, drilled custom plate) and feeds the
heater control loop calibration in TP-002.

DR-013 D5 added pressure and airflow instrumentation to the BOM. This test
plan is built around that instrumentation; an earlier qualitative-only
version is superseded.

## Prerequisites

- Mechanical assembly complete (chamber, plenum, plate, exhaust path)
- Blower installed and TRIAC-controllable
- ESP32 firmware running with logging stream (TC channels + dP_plate channel)
- No heater operation required (cold test — Stage 1 specifically forbids heat)
- Procedural rule (DR-013 D2): no blower runs above ~30% duty without beans
  loaded until plate-float behavior is characterized in Test 1.1

## Equipment

| Instrument | BOM | Used for |
|---|-----|---|
| Differential pressure sensor | PRESS-001 (Sensirion SDP810-500Pa) | Plate dP, bed dP — logged via ESP32 |
| Pressure taps + tubing | PRESS-TAP-001 | Tap pairs through plenum and chamber walls |
| Vane anemometer | ANEMO-001 | Exhaust CFM at outlet — manual reading |
| Clamp ammeter | (existing) | Motor current cross-check vs. CT-001 |
| Tissue strips | — | Visual flow-pattern sketches as supplement to logged data |

### Tap configuration

Two reconfigurable tap pairs feed the single SDP810 via silicone tubing:

- **Plate dP:** + tap in plenum (just below distributor plate); − tap above
  plate (in lower chamber, above bed if loaded)
- **Bed dP:** + tap above plate; − tap above bed (upper chamber)

Swap tubing between configurations during the test. Document which
configuration each row reflects.

### Plate as flow meter (calibration target)

Once SDP810 is installed and ANEMO-001 anchors a CFM reading at one duty
point, the distributor plate becomes its own flow meter for subsequent runs:

    CFM ≈ k × √(dP_plate)

where k is calibrated from the anemometer-anchored point. This lets later
tests (TP-002 thermal, TP-006 first roast) run without the anemometer.

## Test Procedure

### Test 1.1 — Plate dP curve (no beans)

Plate dP swept against blower duty, with the procedural-rule cap honored.

1. Verify chamber is empty and plate is properly seated on ring.
2. Tubing in **plate dP** configuration.
3. Set blower duty to 10%; record dP_plate, motor current, qualitative plate
   behavior (floats? rattles? still?).
4. Step duty: 20%, 30%. **Stop at 30%** for any sign of plate float (lift,
   rattle, displacement). If plate floats: log the duty and dP at which it
   started; abort the rest of Test 1.1; deploy DR-013 D2 reactive
   mitigation (rivet ring lip, then re-run).
5. If plate stays put through 30% — plate-float concern is closed for the
   FengYoo / 22%-open configuration. Continue to Test 1.2 with beans loaded
   (which pin the plate) before stepping to higher duty.

**Pass criteria:** plate dP rises monotonically with duty; plate stays seated
through 30% duty cold; recorded curve will anchor flow-meter calibration in
1.4.

### Test 1.2 — Fluidization onset and window (beans loaded)

1. Load 113 g green coffee beans into chamber.
2. Tubing remains in **plate dP** configuration; switch to **bed dP** for one
   sweep at the end.
3. From 20% duty, step up in 5% increments. At each step record:
   - Blower duty (%)
   - dP_plate (Pa)
   - Motor current (A) cross-check vs. CT-001
   - Bed motion: still / shifting / lifting / fluidized / circulating / venting
   - Photo or short video at each step
4. Identify and record:
   - **U_mf duty** — duty at which beans first lift (minimum fluidization)
   - **Operating duty band** — duty range producing good circulation
   - **Entrainment duty** — duty at which beans start being carried into
     exhaust (must stay below this in operation)
5. At the well-fluidized duty, swap tubing to **bed dP** configuration; record
   bed dP. Compare to plate dP — ratio plate-dP / bed-dP indicates whether
   the plate is dominating the flow distribution (good) or being bypassed
   (channeling).

**Pass criteria:**
- Operating duty band exists (entrainment duty > U_mf duty by a comfortable
  margin)
- Bed motion at operating duty is reasonably even — no persistent dead zone
  > 25% of bed area visually
- Plate dP / bed dP ratio ≥ 0.3 (plate dominates) ideally; ratio < 0.1
  indicates probable channeling and triggers DR-013 D1 reactive Plan B
  (install MESH-001 disc on plate)

### Test 1.3 — Anemometer anchor (one-time CFM measurement)

1. At the well-fluidized duty point from Test 1.2, hold ANEMO-001 vane in
   the exhaust outlet stream.
2. Record exhaust velocity (m/s); compute CFM from outlet area.
3. Record dP_plate at the same duty point — this is the (CFM, dP_plate)
   anchor pair.
4. Repeat at one or two additional duty points to confirm the
   √(dP) relationship holds.

**Pass criteria:** measured CFM at operating duty falls in the 12–18 CFM
hot-equivalent range from architecture.md airflow budget. (Note: this is a
cold measurement; hot-air density correction applies for operation — see
architecture.md T5.)

### Test 1.4 — Plate flow-meter calibration

From the anchor pair(s) in Test 1.3, fit:

    k = CFM / √(dP_plate)

Record k in test results; this constant carries forward into TP-002 and
TP-006 so the anemometer is not needed for routine roasts.

### Test 1.5 — Blower characterization

At each blower duty (10%, 25%, 50%, 75%, 100% — empty chamber to avoid
entrainment at high duty):

1. Record motor current (A)
2. Record dP_plate (Pa)
3. Note qualitative noise level and any vibration or mechanical issue
4. Note whether the bypass-cooling exhaust stream is well-separated from
   the working air (DR-011 critical assumption)

## Data to Record

Logged via ESP32 (suggested CSV columns):
`timestamp, blower_duty_pct, motor_current_A, dP_plate_Pa, dP_bed_Pa,
TC1_C, TC2_C, TC3_C, notes`

Manual log (for entries that don't fit the stream):

| Test | Duty % | dP_plate (Pa) | dP_bed (Pa) | Anemo CFM | Bed motion | Plate float? | Notes |
|---|---|---|---|---|---|---|---|
| 1.1  | | | n/a | n/a | n/a | | |
| 1.2  | | | | | | | |
| 1.3  | | | | | | n/a | |
| 1.5  | | | n/a | n/a | n/a | | |

## Failure Response

| Symptom | Likely cause | Action |
|---|---|---|
| Plate dP rises but bed dP stays ~0 | Channeling — air bypassing bed evenly | Install MESH-001 (DR-013 D1 Plan B); re-run 1.2 |
| Plate dP stays low across all duty | 22% open area too high for our airflow | Install MESH-001; re-run 1.1–1.3 |
| Plate floats at low duty | DR-013 D2 condition; FengYoo geometry assumed safe but didn't pan out | Rivet small SS lip to underside of clamp ring (D2 reactive); re-run 1.1 |
| No operating duty band (entrainment ≈ U_mf) | Chamber L/D too high (T3) — Geldart D slugging | Switch to other chamber size (DR-001 dual-chamber test) |
| Persistent dead zone > 25% of bed | Baffle / inlet jet not redirecting properly | Inspect DR-009 ramp; consider T2 second perforated baffle |
| Plate dP / bed dP < 0.1 with FengYoo + MESH-001 (60-mesh+) | Even mesh insufficient | Build DIY-drilled custom plate at 4% open area (DR-013 D1 Plan C) |

## Traceability

- Design: `docs/system/architecture.md` (airflow budget T1, T3, T5),
  `docs/system/design-log.md` DR-013 (this test's instrumentation source),
  DR-008 (plate-float math), DR-009 (deflector ramp), DR-011 (motor),
  DR-012 (round plenum)
- BOM: PLATE-001A/B, MESH-001, PRESS-001, PRESS-TAP-001, ANEMO-001, BLW-001
- Downstream: TP-002 thermal (uses k flow-meter constant from Test 1.4),
  TP-006 first roast (operates inside the duty band identified here)

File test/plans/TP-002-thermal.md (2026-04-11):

# TP-002: Thermal Characterization Test

## Purpose
Characterize heater response, thermal lag, steady-state temperatures, and overall
thermal performance of the air heating system.

## Prerequisites
- TP-001 passed (airflow verified)
- Heater installed and wired through SSR
- All three thermocouples installed and reading
- ESP32 firmware running with sensor acquisition and serial logging
- Safety over-temp shutdown verified (can be tested as part of this procedure)

## Equipment
- Full roaster assembly (no beans for most tests)
- Serial terminal or Artisan connected for data logging
- Stopwatch (or rely on firmware timestamps)
- IR thermometer (optional, for spot-checking external surface temps)
- Fire extinguisher (mandatory)

## Test Procedure

### Test 2.1: Heater Step Response (No Beans)
1. Set blower to the nominal fluidization speed from TP-001
2. Allow system to reach ambient steady state (~2 min with blower running)
3. Record baseline TC1, TC2, TC3
4. Step heater to 50% duty
5. Log TC1, TC2, TC3 every second until TC1 stabilizes (< 1°C change over 30 sec)
6. Record steady-state temps and time to reach them
7. Step heater to 0%. Log cool-down until TC1 returns within 10°C of ambient
8. Repeat steps 4-7 at 75% and 100% duty

**Key metrics:** Time constant (63% of final ΔT), steady-state TC1 at each duty,
TC2-to-TC1 ratio, TC3-to-TC1 ratio, cool-down time.

### Test 2.2: Thermal Sweep
1. Blower at nominal speed
2. Step heater through 0%, 20%, 40%, 60%, 80%, 100% in 2-minute holds
3. Record steady-state (or near-steady) TC1, TC2, TC3 at each point

**Purpose:** Map the heater duty to process air temperature curve. This is the
primary characterization data for future PID tuning.

### Test 2.3: Safety Shutdown Verification
1. Set heater to 100%, blower to nominal
2. Monitor TC1 as it climbs
3. Verify that the firmware safety layer triggers heater-off when TC1 exceeds
   `SAFETY_MAX_PROCESS_TEMP_C` (280°C default)
4. Verify the system enters fault state and heater remains off
5. Verify that RESET command clears the fault only after temps drop

**Pass criteria:** Safety shutdown fires within 2 seconds of threshold crossing.
Heater is provably off (SSR de-energized, TC1 begins dropping).

### Test 2.4: External Temperature Check
1. After 10 minutes at 80% heater duty, use IR thermometer to check:
   - Heater can exterior
   - Plenum exterior
   - Chamber exterior
   - Any wiring or connector near heat sources
2. Record temperatures

**Pass criteria:** No external surface exceeds 60°C where an operator might touch.
Wiring insulation temps are within rated range.

## Data to Record

| Test | Heater % | Blower % | TC1 (°C) | TC2 (°C) | TC3 (°C) | Time (s) | Notes |
|---|---|---|---|---|---|---|---|
| | | | | | | | |

## Failure Response
- If steady-state TC1 is too low at 100%: heater undersized or too much heat loss; evaluate insulation
- If time constants are very long (> 60s to 63%): heater-to-air coupling is poor; review heater can geometry
- If safety shutdown doesn't trigger: STOP testing, debug firmware immediately
- If external temps are excessive: add insulation or heat shielding before proceeding

## Traceability
- Design: `docs/electrical/heater-circuit.md`, `docs/system/architecture.md`
- Safety: `docs/software/safety-logic.md`

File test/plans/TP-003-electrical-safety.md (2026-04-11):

# TP-003: Electrical Safety Test

## Purpose
Verify that the electrical system meets basic safety requirements before applying
power to the complete roaster assembly.

## Prerequisites
- All electrical wiring complete
- System NOT powered for initial checks

## Equipment
- Multimeter (resistance and continuity mode)
- Megger / insulation resistance tester (preferred) or multimeter on high-ohm range
- Clamp ammeter
- Ground-bond tester or low-resistance ohmmeter

## Test Procedure

### Test 3.1: Ground Continuity
1. Disconnect from mains
2. Measure resistance between mains earth pin and each metal chassis component:
   - Chamber body
   - Plenum body
   - Heater can body
   - Any metal enclosure panels
3. Record all readings

**Pass criteria:** All readings < 0.1 ohm

### Test 3.2: Mains-to-Low-Voltage Isolation
1. Disconnect from mains
2. Disconnect ESP32 board from circuit (to protect it)
3. Measure resistance between:
   - Mains L to any low-voltage conductor (ESP32 side)
   - Mains N to any low-voltage conductor
   - Mains L to chassis ground (should be open, not shorted)
   - Mains N to chassis ground (should be open, not shorted)
4. If megger available: test at 500V DC

**Pass criteria:** > 1 Mohm between mains and low-voltage. No shorts between L/N and ground.

### Test 3.3: Strain Relief and Mechanical Integrity
1. Inspect all cord entries for proper strain relief
2. Apply moderate tug test (~10 lb pull) to mains cord
3. Verify no terminal pulled loose
4. Inspect all wire terminations for exposed conductor, cold joints, or loose screws
5. Verify mains wire gauge is adequate for current (14 AWG minimum for 15A)

**Pass criteria:** All connections remain secure. No exposed conductors. Wire gauge correct.

### Test 3.4: First Power-On (Smoke Test)
1. Reconnect all boards
2. Verify hard disconnect is OFF
3. Plug into mains outlet (with GFCI if available)
4. Turn on hard disconnect
5. Verify ESP32 boots (serial output visible)
6. Verify no smoke, unusual smells, or sparks
7. Measure mains current draw with no heater/blower active (should be < 0.5A — PSU only)
8. Command blower to 50% — verify operation and measure current
9. Command heater to 10% for 5 seconds — verify SSR clicks and measure current
10. STOP command — verify everything shuts down

**Pass criteria:** No smoke, no sparks, currents within expected ranges, ESP32
responsive, STOP works immediately.

### Test 3.5: SSR Failure Mode Check
1. Command heater to 50%
2. Pull SSR control signal (disconnect GPIO wire to SSR gate)
3. Verify heater de-energizes immediately (SSR should default off without gate signal)
4. Reconnect and verify normal operation resumes

**Pass criteria:** SSR defaults to OFF when control signal is removed.

## Data to Record

| Test | Measurement | Value | Pass/Fail | Notes |
|---|---|---|---|---|
| | | | | |

## Failure Response
- Ground continuity failure: DO NOT proceed. Fix grounding before any further testing
- Isolation failure: DO NOT proceed. Find and fix the short/leakage path
- Smoke test failure: Disconnect immediately. Diagnose root cause before retry

## Traceability
- Design: `docs/electrical/power-distribution.md`, `docs/electrical/safety-interlocks.md`

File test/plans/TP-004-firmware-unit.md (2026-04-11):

# TP-004: Firmware Unit Test Plan

## Purpose
Verify correctness of firmware modules through automated unit tests and
targeted manual bench tests on real hardware.

## Prerequisites
- PlatformIO installed
- ESP32 dev board available (for on-hardware tests)
- Firmware compiles clean (`pio run`)

## Automated Unit Tests

Run with: `pio test` (from `firmware/` directory)

### Safety Module (`test/test_safety.cpp`)
- [ ] Initial state is OK after `safety_init()`
- [ ] `safety_trigger_fault()` transitions to fault state
- [ ] Fault state reports `safety_heater_allowed() == false`
- [ ] `safety_reset()` clears fault when conditions are met
- [ ] Multiple fault types are tracked correctly
- [ ] Over-temp check triggers at threshold
- [ ] TC fault detection triggers safety fault

### Sensor Module (planned: `test/test_sensors.cpp`)
- [ ] Valid reading produces correct temperature
- [ ] NaN reading sets fault flag
- [ ] Fault flag clears on next good reading
- [ ] All three TC channels independent

### Heater Module (planned: `test/test_heater.cpp`)
- [ ] Duty 0% produces no output
- [ ] Duty 100% produces continuous output
- [ ] Duty 50% produces correct on/off ratio within period
- [ ] `heater_force_off()` immediately stops output regardless of duty
- [ ] Safety override prevents output when not allowed

### Command Module (planned: `test/test_control.cpp`)
- [ ] HEAT command sets duty correctly
- [ ] BLOW command sets speed correctly
- [ ] STATUS returns well-formed data line
- [ ] RESET command calls safety reset
- [ ] STOP command forces everything off
- [ ] Malformed commands return ERR without crashing
- [ ] Buffer overflow on long input is handled

## Manual Bench Tests (on hardware)

### Bench 4.1: Serial Communication
1. Flash firmware to ESP32
2. Open serial terminal at 115200 baud
3. Verify startup messages appear
4. Send each command and verify response format
5. Send malformed commands and verify ERR responses

### Bench 4.2: Sensor Read (requires TC amplifier boards wired)
1. With TCs at room temp, verify all three read ~20-25°C
2. Hold TC1 in warm water, verify reading increases
3. Disconnect a TC, verify fault detection

### Bench 4.3: SSR Output (requires SSR wired, NO heater element)
1. Set HEAT to 50%
2. Measure SSR output with multimeter or LED indicator
3. Verify ~500ms on / ~500ms off cycle
4. Set HEAT to 0%, verify SSR stays off
5. Set HEAT to 100%, verify SSR stays on

## Data to Record

| Test | Result | Notes |
|---|---|---|
| Automated test suite | PASS / FAIL (attach log) | |
| Bench 4.1 | | |
| Bench 4.2 | | |
| Bench 4.3 | | |

## Traceability
- Code: `firmware/src/`, `firmware/test/`
- Architecture: `docs/software/firmware-architecture.md`

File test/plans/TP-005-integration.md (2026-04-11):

# TP-005: Full System Integration Test

## Purpose
Verify that all subsystems work together as an integrated system before
attempting a real roast. This is a hot test with beans but not a roast —
the goal is system verification, not coffee production.

## Prerequisites
- TP-001 passed (airflow verified)
- TP-002 passed (thermal behavior characterized)
- TP-003 passed (electrical safety verified)
- TP-004 passed (firmware unit tests passing)
- All mechanical, electrical, and firmware subsystems assembled and individually tested
- Artisan connected and receiving data (or serial logging confirmed)

## Equipment
- Complete roaster assembly
- 113g green coffee beans
- Serial terminal or Artisan on host PC
- Fire extinguisher (mandatory)
- Timer

## Test Procedure

### Test 5.1: Cold Start Sequence
1. System powered off. Verify hard disconnect is OFF
2. Turn on hard disconnect
3. Verify ESP32 boots and reports ready state on serial
4. Verify all three TCs reading ambient (~20-25°C)
5. Verify safety state is OK
6. Command BLOW 50 — verify blower starts
7. Command STATUS — verify all fields populated and sensible

**Pass:** System boots clean, all sensors read, blower responds, serial interface works.

### Test 5.2: Fluidization Verification
1. Load 113g green coffee beans
2. Command blower to fluidization speed (from TP-001 results)
3. Verify beans are fluidizing (visual check)
4. Verify TC2 (bean bed) is reading and responding to bean motion
5. Run for 2 minutes, monitor for mechanical issues

**Pass:** Beans fluidize reliably. TC2 reads a stable value. No rattling, vibration, or bean ejection.

### Test 5.3: Heated Run with Beans
1. Beans still loaded, blower at fluidization speed
2. Command HEAT 30 — monitor TC1 rise
3. At TC1 steady state, command HEAT 50
4. Monitor TC1, TC2, TC3 for 5 minutes
5. Verify: TC1 > TC2 > TC3 makes physical sense (may vary — document actual behavior)
6. Verify Artisan (or serial log) is recording all data
7. Command HEAT 0 — monitor cool-down
8. Verify cool-down curves are smooth and physically sensible

**Pass:** All three TCs respond in a physically coherent way. Data stream is
continuous with no dropouts. Heater control is responsive.

### Test 5.4: Safety Shutdown Test (Under Load)
1. With beans, blower running, heater at 50%:
2. Temporarily lower `SAFETY_MAX_PROCESS_TEMP_C` in firmware to a value just
   above current TC1 reading (or wait for TC1 to approach threshold)
3. Verify safety system triggers and heater shuts off
4. Verify serial reports fault state
5. Verify heater commands are rejected while in fault
6. Command RESET after temps drop
7. Verify normal operation resumes

**Pass:** Safety shutdown is fast and reliable under real operating conditions.

### Test 5.5: Emergency Stop
1. System running hot with beans
2. Command STOP
3. Verify heater off AND blower off immediately
4. Time how long until chamber is safe to handle

**Pass:** STOP is immediate and complete.

### Test 5.6: Sustained Run (Soak Test)
1. Fresh start with beans
2. Run at moderate heater duty (40-60%) for 15 minutes continuous
3. Monitor for:
   - Temperature drift or oscillation
   - Mechanical vibration developing
   - Unusual smells (not coffee-related)
   - Wire or connector heating
   - Data stream dropouts
4. After 15 minutes, cool down and inspect

**Pass:** System runs stable for the full duration. No anomalies.

## Data to Record

Log the full data stream (Artisan or serial CSV) for every test.

| Test | Duration | Observations | Pass/Fail | Notes |
|---|---|---|---|---|
| 5.1  | | | | |
| 5.2  | | | | |
| 5.3  | | | | |
| 5.4  | | | | |
| 5.5  | | | | |
| 5.6  | | | | |

## Failure Response
- Any safety failure: STOP, diagnose, do not proceed to TP-006
- Data dropouts: check serial connection, firmware timing, buffer overflows
- Thermal anomalies: check insulation, heater coupling, TC placement
- Mechanical issues: inspect fasteners, alignment, vibration sources

## Traceability
- All prior test plans: TP-001 through TP-004
- System design: `docs/system/block-diagram.md`

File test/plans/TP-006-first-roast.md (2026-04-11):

# TP-006: First Roast Commissioning

## Purpose
Execute the first real coffee roast. The goal is to safely reach and pass first
crack, collect a complete dataset, and identify improvements for subsequent roasts.
This is NOT about producing great coffee — it is about proving the system works
end-to-end and collecting characterization data.

## Prerequisites
- TP-005 passed (full integration test)
- All safety systems verified under load
- Artisan connected and logging
- Operator has read and understands safety interlock behavior
- Operator has reviewed TP-002 thermal data (knows expected temp ranges)

## Equipment
- Complete roaster assembly
- 113g green coffee beans (suggest a forgiving single-origin, medium density)
- Cooling tray or colander for dumping roasted beans
- Fire extinguisher within arm's reach (mandatory, non-negotiable)
- Timer
- Notebook for manual observations
- Optional: sound recorder or phone for first-crack audio

## Pre-Roast Checklist

- [ ] TP-005 passed within the last 7 days
- [ ] All mechanical fasteners checked
- [ ] Exhaust path clear of chaff from prior tests
- [ ] Fire extinguisher present and charged
- [ ] Artisan connected and logging confirmed
- [ ] Room ventilation adequate (open window or range hood)
- [ ] Hard disconnect accessible
- [ ] Operator is not distracted

## Roast Procedure

### Phase 1: Startup
1. Power on system, verify ESP32 boot and sensor readings
2. Set blower to fluidization speed (from TP-001/TP-005)
3. Load 113g green coffee beans
4. Verify fluidization is good (visual)
5. Record initial TC1, TC2, TC3 readings

### Phase 2: Heat Application (Conservative Ramp)
6. Command HEAT 20 — hold for 60 seconds, observe TC1 rise
7. Command HEAT 40 — hold for 60 seconds
8. Command HEAT 60 — hold for 60 seconds
9. Command HEAT 80 — hold and monitor
10. Continue adjusting heater to maintain TC1 in a safe climbing range
11. **Do not exceed 100% for extended periods on first roast**

### Phase 3: Drying Phase
12. Observe TC2 (bean bed temp) — beans are drying when TC2 climbs through ~150°C
13. Note any color change or grassy smell (drying to yellowing transition)
14. Record TC2 at color-change observation

### Phase 4: Maillard / Development
15. Beans transition from yellow to light brown
16. TC2 climbing through ~170-190°C
17. Monitor rate of TC2 change — should be accelerating
18. Listen for first crack (sharp popping sounds, ~195-205°C on TC2, depends on setup)

### Phase 5: First Crack
19. **Record TC2 at first crack onset**
20. Note time from heat-on to first crack
21. Reduce heater to 40-50% (or lower) to slow development
22. Let first crack complete (popping tapers off, ~30-90 seconds)
23. **For first roast: stop here.** Do not push to second crack.

### Phase 6: Cool-Down
24. Command HEAT 0
25. Keep blower running at full speed
26. Monitor TC2 descent
27. When TC2 < 50°C, dump beans to cooling tray
28. Continue blower for 30 seconds to cool internals
29. Power down

## Key Data Points to Record

| Event | TC1 (°C) | TC2 (°C) | TC3 (°C) | Time (mm:ss) | Heater % | Notes |
|---|---|---|---|---|---|---|
| Heat on | | | | 0:00 | | |
| Yellowing | | | | | | |
| First crack start | | | | | | |
| First crack end | | | | | | |
| Heater off | | | | | | |
| Beans dumped | | | | | | |

## Post-Roast Review

### Immediate
- [ ] Save Artisan log file
- [ ] Photograph the roasted beans
- [ ] Note roast color and uniformity (even vs. tipping/scorching)
- [ ] Note any off-smells during roast
- [ ] Inspect distributor plate for obstructions
- [ ] Inspect exhaust path for chaff accumulation
- [ ] Check all external surface temps (IR thermometer)

### Analysis (within 24 hours)
- [ ] Review Artisan curves: are they smooth and physically coherent?
- [ ] Calculate rate-of-rise (RoR) from TC2 data
- [ ] Compare TC1/TC2/TC3 relationships to TP-002 empty-chamber data
- [ ] Identify the effective heat transfer: how much did beans affect thermal behavior?
- [ ] Document total roast time, development time ratio
- [ ] List what went well and what needs changing

### Taste (24-48 hours post-roast)
- [ ] Brew and taste the coffee
- [ ] Note: underdeveloped / well-developed / overdeveloped
- [ ] This is not about quality — it's about whether the roast reached the intended level

## Failure Modes During Roast

| Symptom | Action |
|---|---|
| Safety shutdown triggers | Note temps, do not override. Cool down. Investigate. |
| Beans stop fluidizing | Reduce heater, increase blower. If stuck: STOP. |
| Smoke beyond normal roast smoke | Reduce heater. If excessive: STOP. |
| Strange electrical smell | STOP immediately. Disconnect power. Investigate. |
| First crack doesn't arrive by 20 min | Heater may be undersized. End roast, review data. |
| TC readings go erratic | STOP. Check TC connections. |

## Success Criteria

This first roast is successful if:
1. The system operated safely from start to finish
2. Beans reached at least first crack
3. A complete data log was captured
4. No mechanical, electrical, or firmware failures occurred
5. Enough data was collected to plan improvements for roast #2

## Traceability
- All prior test plans: TP-001 through TP-005
- Design: `claude.md` (v1 build intent)
- Thermal data: TP-002 results

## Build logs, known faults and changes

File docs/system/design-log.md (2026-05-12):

# Design Log

Running record of design decisions, findings, and rationale. Newest entries first.

---

## 2026-05-12 — DR-017 Host platform: Pi 5 + integrated 7" HDMI display

### Decision

The Artisan host (per DR-016) is a **Raspberry Pi 5 (8 GB)** with the on-hand
generic 7" HDMI touchscreen, both mounted integrated to the baseplate in a
new **Zone E**, USB-tethered to the ESP32. iPad is a read-only secondary
view over WiFi via Artisan's WebLCDs.

Transport between Pi and ESP32 is **USB serial** (Variant A) for v1. The
firmware command parser is structured transport-agnostically so a WiFi /
TCP-socket transport (Variant B) can be added in v2 without re-architecting.

### Why Pi 5 over laptop / Pi 4 / iPad-only

| Option | Why not |
|---|---|
| Laptop tethered | Fragile (USB jiggle, sleep, screensaver), not physically attached, defeats "attached UI" goal |
| Pi 4 | Sufficient for Artisan alone but no headroom for future image-stream or analysis work; Pi 5 is only ~$25 more |
| iPad as host | Artisan does not run on iOS — period. Closes off the entire control path |
| iPad as VNC client | Adds latency, tiny tap targets, locks the iPad to one role while tethered |

iPad survives in the architecture as a **passive remote view** via WebLCDs
over LAN — free bonus once the Pi is on WiFi, no extra parts.

### Why USB serial, not WiFi/TCP

WiFi/TCP is supported natively by Artisan (Modbus TCP / WebSocket device
profiles) and the ESP32 has the radio for free. It's tempting for v1. Rejected
because:

- USB is lower-latency, has no provisioning / network-credential / NTP
  surface area, and fails into a single well-understood mode (cable yank →
  serial watchdog → safe state per DR-016).
- WiFi adds WPA provisioning, captive-portal flow, time-sync, security
  model, mDNS for service discovery — meaningful firmware burden for no v1
  control-loop benefit.
- The firmware structure that supports a clean v2 migration is just: keep
  command parsing decoupled from the transport layer. Free to design that
  way from the start.

WiFi remains in the architecture for the WebLCDs bridge (Pi → iPad), which is
a totally separate path from the ESP32 control link.

### Zone E — new baseplate region

`baseplate-layout.md` currently defines 4 zones:

- Zone A — motor (rear angle-iron extension)
- Zone B — heater can
- Zone C — plenum + chamber
- Zone D — electronics tray (front angle-iron extension)

**Zone E (new)** carries the Pi 5 + display as an integrated unit, mounted
to the front of the baseplate above or adjacent to Zone D. Exact geometry
deferred until Pi 5 and display dimensions are confirmed alongside the BOM
lock; `baseplate-layout.md` will be updated in a follow-up commit.

Thermal separation from Zone B/C is the key constraint — Pi 5 is rated 0–50°C
ambient operating; passive radiation from the heater can must not raise the
Pi enclosure ambient above that. A reflective baffle between Zone B/C and
Zone E is the likely mitigation.

### Software stack

- Raspberry Pi OS 64-bit (Bookworm or current)
- `/boot/firmware/config.txt`: `usb_max_current_enable=1` to unlock the
  1.6 A USB rail (required per G2)
- Artisan latest stable, ARM64 build, auto-launch fullscreen on boot
- WebLCDs enabled (Artisan Config → Logging → WebLCDs); accessible at
  `http://<pi-ip>:7000` on the LAN
- VNC + SSH enabled for headless debug access
- Serial device: ESP32 enumerates as `/dev/ttyUSB0` or `/dev/ttyACM0`; udev
  rule pins device path for stability across reboots

### Power architecture

Display draws USB 5 V from the Pi itself. Pi 5's USB rail can supply up to
1.6 A total when powered from the official 27 W (5 V / 5 A) PSU. Budget:

- 7" display: estimated 0.7–1.0 A (verification gate G1 below)
- ESP32 via USB: 0.1–0.2 A
- Headroom for one extra peripheral: ~0.4 A

This is tight but workable. If display + ESP32 exceeds budget, fallback is
a powered USB hub (cheap, adds one component).

### Verification gates

- **G1 — RESOLVED 2026-05-12.** Display is a generic 5" × 7" HDMI panel
  (on hand) with both HDMI for video and USB for power + touch (USB HID).
  Single USB cable from Pi 5 carries both power and touch input. No
  separate display PSU needed; no `UI-008` BOM line. micro-HDMI → HDMI
  cable (`UI-005`) handles video; one of Pi 5's USB-A ports carries the
  combined power + touch path.
- **G2 — RESOLVED 2026-05-12.** Pi 5 ships with a conservative
  600 mA total USB current cap by default. With the official 27 W
  (5 V / 5 A) PSU (`UI-002`) connected AND `usb_max_current_enable=1`
  set in `/boot/firmware/config.txt`, the cap raises to 1.6 A total.
  Budget at the elevated cap:

  | Load | Estimated draw |
  |---|---|
  | 5×7 display (backlight + touch) | 0.7–1.0 A |
  | ESP32 via USB serial | 0.1–0.2 A |
  | **Total worst case** | **1.2 A** |
  | **Headroom under 1.6 A cap** | **~0.4 A** |

  Workable. If TP-001 commissioning shows brown-outs on the display at peak
  backlight (e.g. cold-start), fallback is a powered USB hub on the display
  USB lead (reactive `UI-009`, not built now). The 1.6 A flag goes into the
  Pi's first-boot setup checklist alongside SSH/VNC enable.
- **G3 — OPEN (physical mockup required).** Pi 5 + display + existing
  Zone D electronics tray must fit on the baseplate without violating the
  heater-can thermal exclusion zone. Now bounded by known dimensions:
  display ~152 × 203 mm (~6" × 8" bezel estimated), Pi 5 85 × 56 mm
  mounted directly behind display. Zone E geometry per
  `baseplate-layout.md` §5. Verify with cardboard mockup before drilling
  any Zone E mounting holes.

### BOM impact

New `UI-*` family. Display itself is on hand — no BOM line.

| Item | Description |
|---|---|
| `UI-001` | Raspberry Pi 5, 8 GB |
| `UI-002` | Official Pi 5 27 W USB-C PSU |
| `UI-003` | Pi 5 active cooler |
| `UI-004` | microSD 64 GB A2 V30 (boot drive) |
| `UI-005` | micro-HDMI → HDMI cable, ~12" |
| `UI-006` | USB-A → ESP32 short cable with ferrite |
| `UI-007` | Zone E mounting hardware (standoffs / bracket from BASE-001 offcut) |

Estimated total: ~$115. Display PSU not needed (Pi USB-powered).

### What this opens up

- Local-attached UI without a laptop tether
- iPad-on-LAN as a passive observation surface (no extra parts)
- v2 transition to WiFi/TCP control transport, with firmware already
  structured to drop it in
- Future on-host image analysis (color tracker, drum-position camera, etc.)
  has headroom on Pi 5

### What this closes off

- Laptop-tethered operation is now the fallback / debug path, not the
  primary
- iPad-as-primary-host is permanently ruled out

### Files touched

- `docs/system/design-log.md` (this entry)
- `bom/bom-master.csv` (7 new UI-* rows)
- `docs/mechanical/baseplate-layout.md` — Zone E to be added in follow-up
  once G1–G3 resolve

---

## 2026-05-12 — DR-016 Operator UI architecture: Artisan-as-UI + minimal safety panel

### Decision

Two coupled decisions about how the operator interacts with the roaster in v1:

**D1 — Hardware Heater Enable switch on the SSR control line.** A front-panel
SPST toggle is wired in series with the ESP32 → SSR control signal (low-voltage
~5V / ~10mA path; no mains-side current). The ESP32 also reads the switch
state as a digital input so firmware refuses to assert heater duty when
disabled, regardless of upstream commands. This makes the heater authority
hierarchy explicit and physical:

| Level | Mechanism | Use case |
|---|---|---|
| 1 | Firmware control loop / `COOL` command | Normal operation, graceful cooldown |
| 2 | Hardware Heater Enable switch | Operator override, commissioning, distrust firmware |
| 3 | Thermal fuses (`THFUSE-001` / `THFUSE-002`) | SSR-shorted runaway last resort |
| 4 | DPST main disconnect (`SW-001`) | Total kill |

Each level is independent of the levels below it. Honors the CLAUDE.md safety
doctrine ("the safety system should always be able to force heater off") and
extends it to the operator.

**D2 — Artisan is the operator UI; no physical pots, mode switch, or screen
on v1.** Every v1 roast is a characterization roast and Artisan is going to
be running for logging anyway, so a tethered host is already a hard
requirement. Adding panel-mounted setpoint controls (heater% / blower% pots,
AUTO/MANUAL toggle, OLED + encoder) creates a second source of truth for
setpoints and a non-trivial firmware burden for no operational gain in v1.

Minimal v1 panel:

| Component | Purpose |
|---|---|
| DPST main disconnect (`SW-001`, red toggle + cover) | Last-resort kill |
| Heater Enable switch (`SW-002`, new) | Defense-in-depth on SSR control |
| POWER LED (`LED-001`, new) | "Mains is hot" at-a-glance |
| FAULT LED (`LED-002`, new) | Latched fault from safety layer |

No pots, no encoder, no screen.

### Why not pots / knobs

Considered a "knob = setpoint, Artisan = logger" model where physical pots
drive heater% and blower% directly. Rejected because:

- Every v1 roast is logged, so Artisan must be running anyway — knobs would
  duplicate setpoint authority and create knob-vs-Artisan arbitration.
- Setpoint changes made from knobs would need a separate read-and-log path
  to land in the roast record with the same provenance as Artisan-issued
  commands.
- Closed-loop migration (v2) is now pure software — no physical control
  surface to repurpose or ignore.

The cost of the foreclosure is low: if v2 needs panel setpoints, two ADC pins
and a mode-arbitration block of firmware can be added then.

### USB-drop failure mode

The Artisan-only path makes USB serial integrity safety-relevant. Mitigated
by:

- **Serial watchdog in firmware.** No command received in N seconds → fail
  to safe state: heater 0%, blower retains last value (preserves cooldown),
  FAULT LED on, fault latched until reset. N to be tuned in TP-001; start
  ~5s.
- **Positive-latching USB connector.** Short cable, USB-B or USB-C with
  positive retention; no long flimsy A-to-MicroB.
- **Host discipline.** Laptop/Pi on AC, sleep disabled, screensaver off
  during roast — already implicit in any logged-roast workflow.

### What this closes off

- No panel-mounted setpoint controls in v1.
- No on-device screen / OLED / touch UI in v1.
- No MANUAL/AUTO mode arbitration logic in firmware.

These are explicitly deferred to v2 if and when post-TP-001 data shows they're
warranted.

### What this opens up

The host running Artisan does NOT have to be a laptop. Pi-based attached UI
is the natural next step — captured separately, not in this DR.

### BOM impact

| Action | Item |
|---|---|
| Added | `SW-002` — Heater Enable SPST toggle (low-voltage panel switch) |
| Added | `LED-001` — POWER indicator LED, panel-mount |
| Added | `LED-002` — FAULT indicator LED, panel-mount |

Current-limiting resistors come from the ELEGOO kit (`R3-001`).

### Files touched

- `docs/system/design-log.md` (this entry)
- `bom/bom-master.csv` (3 new rows)

---

## 2026-05-09 — DR-015 BLW-HOUS-001 outlet is axial, not radial — add elbow

### Decision

The Ametek-Lamb 45899-14 fan shell (BLW-HOUS-001) has an **axial** 1.5" pipe
outlet — it exits the dome face of the shell parallel to the motor shaft,
off-center, not radially out the perimeter as the original DR-014 BOM line
described. With BLW-001 mounted shaft-vertical (per baseplate-layout.md §3.1),
the housing outlet therefore points straight up.

**Resolution:** add a 1.5" silicone 90° elbow (new BOM line BLW-ELBOW-001)
between the housing outlet and BLW-COUP-001, redirecting the discharge
horizontal-forward to the heater can. Keep the motor shaft-vertical.

Also: confirmed the housing-to-motor seal needs its own gasket separate from
the motor-included Gasket 566 (added BLW-HOUS-GSK-001), and re-sourced
BLW-HOUS-001 from The Vacuum Factory ($34.95) instead of Amazon ($47–50) —
same OEM PN, ~$12 savings.

### How we got here

DR-014 (2026-05-09) selected 45899-14 to replace a fabricated stovepipe
collector. The BOM line described its outlet as "exits radially at the
discharge band" — that was an assumption not backed by primary-source
inspection. When sweeping the docs after the BLW-001 architecture
confirmation today, two research agents disagreed about the outlet
orientation while looking at the same listings. Pulling the Ace Vacuums
product photo directly settled it: pipe is on the dome face, parallel to the
motor axis, off-center. Photo also makes clear the shell ships without a
gasket ("mounting bolts and gasket must be purchased separately"), and the
motor's Gasket 566 is for the motor-to-bulkhead OEM-application seal, not
the shell-to-disc seal.

### Why elbow > rotate motor

Considered rotating BLW-001 to shaft-horizontal so the axial outlet would
point forward natively. Rejected because shaft-vertical keeps the
cooling-air **intake** (top star grille on the upper cylinder) facing
upward, away from the air train and clear of any chaff path. Shaft-horizontal
would aim that intake sideways — fine in principle but adds a constraint that
the cooling intake must not face anything restrictive or that recycles
discharge air. The elbow costs ~$8 and one minor turn-loss; preserves the
existing baseplate-layout almost unchanged.

### Open verification gates (unchanged from BLW-001 work)

- Caliper-measure the bolt circle on the actual aftermarket motor before
  ordering the housing — must be 4× ø0.150" on ø4.625" BC per the OEM
  datasheet the aftermarket part claims to replicate.
- Confirm the aftermarket motor's outer body diameter at the disc rim
  (~5.78–5.85" / 146–148 mm) seats inside the 45899-14 mouth.

### BOM impact

| Action | Item |
|---|---|
| Modified | BLW-HOUS-001 — outlet description (axial), source (Vac Factory primary, Amazon backup), notes |
| Added | BLW-HOUS-GSK-001 — separate fan-shell-to-motor gasket, ~$5–8 |
| Added | BLW-ELBOW-001 — 1.5" silicone 90° elbow, ~$6–10 |
| Modified | BLW-COUP-001 — notes updated to reflect upstream elbow |

### Files touched

- `bom/bom-master.csv` (BLW-HOUS-001 row + 2 new rows + BLW-COUP-001 row)
- `docs/mechanical/baseplate-layout.md` §3.1 outlet routing row
- `docs/mechanical/drawings/roaster-assembly.scad` blower module geometry +
  comment

---

## 2026-05-05 — DR-013 tangential-entry plenum variant for A/B test

### Decision

**Cut two plenum bodies from the same stovepipe scrap and A/B test inlet
geometry:**

- **Plenum A (baseline):** radial side inlet + DR-009 wall-mounted deflector
  ramp opposite the inlet. Spec unchanged from DR-012.
- **Plenum B (variant):** tangential side inlet, no internal ramp. Inlet jet
  enters along the wall to induce swirl; plenum volume + swirl handle jet
  dissipation in place of the DR-009 spoiler.

Both bodies cut to identical 8" dia × 6" tall so inlet geometry is the only
variable. Same caps, same DR-008 clamp ring, same distributor plate.

### Rationale

The DR-012 ramp is a known-good jet spoiler but the 7× plenum:chamber volume
ratio gives us margin to try a more aerodynamic alternative. Swirling
fluidized bed (SFB) literature reports better radial mixing and more uniform
bed temperature with tangential entry; cyclone separators and the West Bend
Poppery's accidentally-tangential blower discharge are familiar analogues.
With abundant scrap on hand, A/B is cheaper than picking blind.

Test variable: fluidization uniformity at the bean bed (visual + bed
temperature spread if we have multiple probes by then). Decision criterion:
visibly more uniform bed motion or measurably tighter bed-temp spread →
tangential wins for v2; otherwise stick with the ramp.

### Fabrication note — tangential is not just an offset hole

A hole saw cuts perpendicular to the local wall surface, so positioning the
hole off-center on the cylinder circumference still produces a **radial**
stub. Three options for genuine tangential entry, in increasing fab effort:

1. **Angled hole-saw cut.** Pilot perpendicular for bite, then tilt the saw
   toward tangent as it cuts through. Hole comes out elongated; seal the
   stub joint with high-temp RTV. Selected for plenum B — adequate for an
   A/B and reversible-ish.
2. **Flat-and-flange.** Cut a rectangular window on the tangent line, rivet
   a small sheet-metal flange flat to it, mount the stub perpendicular to
   the flange. Reserved for v2 if tangential wins.
3. **Internal turning vane.** Drill radial, add a curved sheet-metal vane
   inside that turns the flow tangential. Vane sees full hot jet — gauge
   accordingly. Not selected; defeats the goal of testing pure tangential.

### Status

Plenum A and B to be cut from the same stock so wall thickness / oxide layer
match. Cure burn (DR-012 M7) before assembly applies to both. Document
which is which with a punch mark or paint dot — visual cues are easy to
forget after the caps go on.

---

## 2026-05-04 — DR-013 pre-build design review

Final design review before any irreversible plenum or distributor-plate fab,
triggered by DR-011 (motor swap), DR-012 (round plenum), and the DR-008 ring
geometry fix landing in the same period. Five decisions captured, one
calculation correction, four new BOM lines, one test-plan rewrite. No
architectural commitments moved — only parameter-level decisions inside
existing commitments.

### D1 — Distributor plate spec: FengYoo plate as-is, mesh staged

PLATE-001A and PLATE-001B are already sourced as 4" 19-ga 304 SS pre-perforated
discs at 22% open area (FengYoo B09SF15S47).

Final spec:

- **Initial config:** FengYoo perforated plate cut to 2.37" / 2.87" per
  chamber, used as-is at 22% open area.
- **Staged Plan B (MESH-001):** 40-mesh 304 SS woven cloth disc per chamber,
  pre-cut and on hand. Installed *over* the perforated plate if TP-001 stage 1
  measurements show plate dP too low (channeling) or visually uneven
  fluidization. Mesh count steps (40 → 60 → 80) double dP at each step.
- **Plan C (deferred):** DIY-drilled custom plates at ~4% open area, only if
  mesh proves insufficient.

The 22% open area is well above the conventional fluid-bed sweet spot and
*may* channel. Two things make "as-is" the right starting point anyway:
(1) the parts are paid for, (2) D5 below adds dP instrumentation so
channeling is now measurable and characterizable rather than guessed at.

### D2 — Plate float: procedural rule is the actual mitigation

Re-derivation of the DR-008 plate-float force at 1" WC over a 2.37" plate:
F = dP × A = 249 Pa × 0.00284 m² = 0.71 N ≈ **72 gf**, not 0.5 kgf as the
DR-008 design-log entry stated. The original entry overstated by ~7×.
DR-008 entry corrected inline below.

Re-examination of "heavier plate" mitigation at the corrected number:

| Stock | Mass (2.37" disc) | Margin vs. 72 gf lift |
|---|---|---|
| 22 ga (0.76 mm) | ~17 g | 4× under |
| 19 ga (FengYoo, 1.06 mm) | ~23 g | 3× under |
| 18 ga (1.27 mm) | ~29 g | 2.5× under |
| 12 ga (2.66 mm) | ~61 g | 0.85× — still under |
| 1/8" plate (3.18 mm) | ~73 g | At threshold |
| 3/16" plate (4.76 mm) | ~109 g | 1.5× over |

Conclusion: **no reasonable sheet gauge clears the lift threshold by mass alone.**
The "heavier plate" decision from the previous turn is **withdrawn** —
re-examination at the corrected force number showed it doesn't work.

Final mitigation strategy:

- **Primary:** procedural rule — no blower runs above ~30% duty without beans
  loaded, until plate behavior is characterized in TP-001.
- **Geometry-assist (free):** at D1's 22% open area, actual plate dP at design
  airflow is far below 1" WC, so actual lift force is much smaller than 72 gf
  and the procedural rule has comfortable margin.
- **Reactive:** if TP-001 shows actual float, rivet a small SS lip to the
  underside of the clamping ring — captures plate edge from above, reversible
  at the ring, no chamber-wall mods.
- **Last resort:** chamber-wall pin remains the irreversible fallback and
  is not built unless the ring lip proves inadequate.

### D3 — Dual top caps: build both

Both top caps drilled — one to 2.5" chamber OD (paired with PLEN-002 ring +
PLATE-001A), one to 3.0" chamber OD (paired with PLEN-003 ring + PLATE-001B).
Bottom cap is permanent (RTV sealed). Honors DR-001 dual-chamber test.

Endcap allocation (3 caps in hand):

- Cap #1: bottom (no center hole, RTV + 3 sheet-metal screws per DR-012)
- Cap #2: top, 2.5" chamber variant
- Cap #3: top, 3.0" chamber variant

One plate per chamber initially; the second plate per chamber (higher dP
variant) is a reactive build only if TP-001 calls for it.

### D4 — Mains current: 20 A bench circuit, NEMA 5-20

DR-011 motor swap pushed total mains load from 12.5 A (heater + 12V-PSU-driven
blower) to 13.5–17 A (heater + universal-AC motor on same circuit). On a 15 A
breaker this exceeds NEC 80% continuous and trips at the high end.

Of the three options (20 A circuit / firmware co-modulation / heater duty cap),
**20 A bench circuit selected** — the only option that doesn't compromise the
control architecture (firmware co-modulation couples heater and blower loops)
or invalidate the 3.0" chamber half of the dual-chamber test (heater duty cap
at 85% caps effective heater at ~1275 W, below the 3.0" chamber's required
input even insulated). v1 is an instrument on the bench, not an appliance for
arbitrary outlets.

Implementation:

- NEMA 5-20 plug on the cord (replaces 5-15)
- 12 AWG cord (already noted in BOM as E5 follow-on)
- Build-level safety label near the cord: **"Requires 20 A circuit (NEMA 5-20).
  Do not plug into a 15 A receptacle."**
- Documented as a v1 operational constraint

### D5 — Instrumentation: add dP sensor + anemometer (raised mid-review)

The pre-build review surfaced that the entire D1/D2 reasoning rested on
"verify plate dP at TP-001" — but the BOM had no instruments to measure
plate dP or airflow magnitude. CT-001 measures motor current (safety
interlock only, not flow). TC1 measures temperature, not pressure. TP-001
in its existing form relied entirely on tissue-paper observation, with
"anemometer or pitot tube" listed as *optional*.

This is a real instrumentation gap. Without it, every plate iteration is
qualitative go/no-go; the project's "instrument first, appliance later"
mission isn't actually instrumented.

Additions:

- **PRESS-001 — Sensirion SDP810-500Pa differential pressure sensor (I2C).**
  ±500 Pa (±2" WC) range fits plate-and-bed dP regime; 0.1% accuracy class;
  shares ESP32 I2C bus with no pin pressure. Two pressure taps with silicone
  tubing back to the sensor; tap pairs reconfigurable across plate, bed, or
  mesh. ~$30.
- **PRESS-TAP-001 — barb fittings + silicone tubing.** Small (~1/8" OD)
  through plenum and chamber walls; reconfigurable. ~$8.
- **ANEMO-001 — handheld vane anemometer.** One-time exhaust CFM spot-checks,
  not logged. 3% accuracy class is fine. ~$25.

Total: ~$60. Single best ROI addition to the project so far — transforms
TP-001 from qualitative go/no-go into a real characterization test, and
enables data-driven iteration on every subsequent plate, mesh, or chamber
swap.

Firmware: SDP810 reads on existing I2C bus; add a `dP_plate` channel to the
Artisan stream. No GPIO-pin-budget impact.

TP-001 rewritten in this same review to use quantified plate dP and measured
exhaust CFM as primary measurands.

### Cross-cutting items confirmed

- **Tip resistance:** threaded-rod tripod legs from the baseplate, extending
  past the baseplate to clamp around the cone reducer or upper chamber.
  Replaces a briefly-considered "chamber drop-through" plenum geometry that
  would have complicated TC-002 mounting and chamber swap. baseplate-layout.md
  §1 updated to reflect.
- **Heat gun teardown** is the next mechanical task and gates the plenum
  side-entry hole position. **Do not drill** the 2.5" hole-saw through
  PLEN-001 until HTR-CAN-001 outlet geometry is known.
- **Pipe material verification:** PLEN-001 must be confirmed bare/oxide-
  blackened mild steel, not galvanized HVAC duct, before any cure-burn or
  cutting. Galvanized = stop and re-source.

### Decisions explicitly NOT touched

DR-008 ring geometry (Option A), DR-009 deflector ramp, DR-011 motor
architecture, DR-012 stovepipe plenum, the 4-zone baseplate layout, and
the safety architecture all stand as written.

### Next actions

1. Order PRESS-001, PRESS-TAP-001, ANEMO-001, MESH-001
2. Heat gun teardown (gates plenum drilling)
3. Verify PLEN-001 material (galvanized check)
4. Cure-burn PLEN-001 outdoors
5. Drill both top caps (2.5" and 3.0")
6. Drill plenum side-entry only after HTR-CAN-001 geometry is known
7. Build clamp rings (PLEN-002, PLEN-003); cut FengYoo plates to size
8. Pre-cut MESH-001 to both plate sizes; hold on standby
9. Stage TRIAC blower firmware while remaining parts are en route

---

## 2026-05-02 — DR-008 ring geometry correction (Option A)

PLEN-002 / PLEN-003 specs had ring ID equal to plate dia (both 2.37" for the
2.5" chamber pair; both 2.87" for the 3.0" pair). Geometrically inconsistent —
with ring ID = plate dia, the plate has no rest surface and would fall through.

**Corrected (Option A — plate sits inside chamber bottom):**

- Top cap hole = chamber OD (2.5" / 3.0") — chamber slides through with slip fit.
- Ring mounted to **underside** of the cap face. Ring ID < chamber ID:
  **2.0" for the 2.5" pair, 2.5" for the 3.0" pair.** Ring's inner face
  protrudes ~0.25" inward of the cap hole as an annular ledge.
- Plate dia = chamber ID (PLATE-001A 2.37" / PLATE-001B 2.87"); drops inside
  the chamber from above and lands on the ring face.
- Chamber bottom rim sits on the same ring face around the plate edge —
  for the 2.5" chamber, the rim's outer edge (R = 1.25") aligns with the cap
  hole edge and the rim's inner edge (R = 1.185") meets the plate edge.

Plate-to-chamber-wall is slip fit. Leak path around the plate edge is
negligible compared to the deliberate distributor perforations.

**Plate float watch (TP-001 add):** at the design dP across the plate
(~1" WC ≈ 249 Pa) over the 2.37" plate area (4.41 in² = 0.00284 m²),
upward force F = dP × A = 249 Pa × 0.00284 m² ≈ 0.71 N ≈ **72 gf**
[CORRECTION 2026-05-04 per DR-013: original entry stated ~0.5 kgf, ~7×
high]. With a 19-ga / ~23 g plate, this still exceeds the plate weight
~3×. With beans loaded, the bed pins the plate; **at startup or empty
operation, the plate may float and bypass the bed.** D1's selected
22%-open-area FengYoo plate operates at much lower actual dP than 1" WC,
which softens this risk substantially. Mitigation strategy finalized in
DR-013 D2 (procedural rule primary; ring lip reactive; chamber-wall pin
last resort).

**Fastening:** Ring is 1/8" SS plate with 3 tapped M4 holes on a bolt circle
outside the cap drill. Machine screws descend from above through the cap
face into the ring threads. No nuts inside the plenum — preserves the
DR-008 ring + plate swap without breaking the DR-012 bottom-cap RTV seal.

PLEN-002, PLEN-003, architecture.md §8 Top Assembly table updated.

---

## 2026-05-02 — DR-012 plenum body: round stovepipe replaces SS steam pan

### Decision

**DR-012: Replace 1/6 SS steam table pan (DR-007) with 8" diameter × 6" tall
black-stovepipe section, both ends pipe-capped.** The bolted-clamp-ring
assembly (DR-008) and deflector ramp baffle (DR-009) carry over with mounting-
substrate changes only. Architecture.md §8 and baseplate-layout.md §1, §3.5,
§6 updated; BOM PLEN-001, PLEN-004, BAFFLE-001 updated.

### Rationale

Black single-wall stovepipe scrap became available at zero cost, displacing
the steam-pan plan (PLEN-001, $4-8 + thrift hunt). The change also resolves
a long-standing geometric awkwardness — a rectangular plenum under a round
chamber.

Diameter sized at **8"**:

| Dia | Floor area | Plenum:chamber (3" chamber) | Verdict |
|-----|---|---|---|
| 6"  | 28 in² | 4× | Marginal — DR-009 ramp has only 1.5" annular margin |
| 8"  | 50 in² | 7× | ✓ Selected — past textbook 3-5× ratio, fits 6×7" Zone-C budget |
| 10" | 79 in² | 11× | Diminishing returns; +50% wall area = more parasitic loss + insulation |

Height set at **6"** by stacking constraints:
- ≥1× inlet diameter (~2.5") between inlet centerline and distributor plate
  for jet dissipation
- ≥2" between inlet centerline and floor for the DR-009 ramp to develop
- +1" headroom for the optional T2 secondary perforated baffle without
  redesign

### Material — black stovepipe specifically

Bare / oxide-blackened mild steel, ~26 ga, rated ~1000°F continuous
(single-wall stove duty). Plenum operates 150-200°C — massively under-spec.

**Excluded materials:** galvanized HVAC duct (zinc outgases at ~390°F /
200°C, exactly where we operate; metal-fume risk in air that passes through
the bean bed before the chimney). Aluminized furnace-plenum pipe would also
be acceptable but stovepipe was on hand.

**Cure burn before assembly** (M7, carried over from PLEN-001 notes): cheap
stovepipe ships with a thin rolling-oil film that smokes off on first heat.
Burn outdoors with a propane torch until smoke stops, before any food-path
roasting.

### Mechanical assembly

The pipe caps double as the structural top and floor — the cap's crimped
skirt seals to the pipe and the flat cap face provides the riveting / bolting
substrate that the steam-pan rim previously gave us:

```
              Chamber tube (2.5" or 3.0" OD SS)
                    │
       ┌────────────┴────────────┐
       │  Top cap: drilled to    │  ← clamp ring (PLEN-002/003) attaches to
       │  chamber OD, ring       │     underside of cap face around the hole
       │  attached underneath    │
       ├─────────────────────────┤
       │                         │
       │     ◊  T2 perf baffle   │  ← future, ~1" below distributor
       │                         │
   ────┤   8" dia × 6" tall      │  ← side-entry stub (PLEN-005),
       │   black stovepipe       │     2.5" hole-saw through wall
       │                         │
       │     ╲                   │
       │      ╲ Deflector ramp   │  ← DR-009, pop-riveted opposite inlet
       │       ╲                 │
       └─────────────────────────┘
              Bottom cap                ← crimped + high-temp RTV + 3 sheet-
                                          metal screws / rivets through skirt
              ↑ 6"
```

- **Top cap:** 2.5" or 3.0" hole drilled to chamber OD; clamp ring on
  underside. **Use M4/M5 machine screws + nyloc nuts, not pop rivets**, so
  the ring + plate pair remains swappable per DR-008. Pop rivets are an
  acceptable one-and-done alternative if v1 commits to a single chamber size.
- **Bottom cap:** slip-fit, sealed at seam with high-temp RTV, retained with
  3 sheet-metal screws or rivets through the cap skirt.
- **Side-entry hole:** 2.5" bi-metal hole saw through the cylindrical wall,
  sized to PLEN-005 stub OD.
- **Snap-lock seam:** if a section is cut from a longer length, lock the
  seam at the cut with a sheet-metal screw so it can't spring open.

### DR-008 / DR-009 carry-over

- **Clamping ring (DR-008):** unchanged spec; attaches to underside of top
  cap face instead of pan flange. Still gasket-sealed via PLEN-004.
- **Deflector ramp (DR-009):** unchanged 3"×4" SS bent to 45°; pop-riveted
  to the cylindrical wall opposite the inlet. Curved wall vs. flat pan wall
  is immaterial — the ramp seats on a chord and the small standoff at the
  edges does not affect jet redirection.

### Cost impact

PLEN-001: $4-8 → $0 (scrap pipe + 2 caps; ~$6 retail if not on-hand).

---

## 2026-05-02 — Sourcing update: baseplate stock + heat gun in hand

- **BASE-001 sourced:** 12" × 24" steel sheet + 1"-class angle iron acquired.
  Sheet is 4" longer than the 20" SCAD assumption (baseplate-layout.md §1),
  giving real Zone-A margin for the vertical-axis vacuum motor (DR-011)
  rather than the borderline 190 mm overhang the prior dimension implied.
  Angle iron earmarked for perimeter stiffening — 12×24" sheet steel of this
  gauge will flex; angle along the long edges plus cross-members at zone
  boundaries gives bending stiffness without ballast. Final framing layout
  deferred until motor footprint is measured.
- **HTR-001 sourced:** Warrior 1500W heat gun (SKU 56434) in hand. Teardown
  is the next mechanical task: measure element resistance (target ~9.6 Ω
  cold for 1500 W / 120 V at room temp), photograph mica former dimensions
  and mounting-tab geometry, identify intake/exhaust footprint. Outputs feed
  HTR-CAN-001 build dimensions and the Zone-B 190 mm placeholder in
  baseplate-layout.md §1.

---

## 2026-04-29 — DR-011 blower upgrade: vacuum motor + TRIAC

### Decision

**DR-011: Replace 12V DC centrifugal blower (DR-003) with bypass-cooled
salvaged universal-AC vacuum motor + TRIAC speed control.** Architecture.md §3
rewritten; BOM, sourcing notes, power schematic, and block diagram updated.

### Rationale

T1 (architecture.md §3) flagged that the Wathai 120 × 32 mm 12 V centrifugal
blower (BLW-001, B08P1S5DBN) had an unverified P-Q curve at the system
operating point. On closer review, blowers of this physical size shut off
around 1.0–1.5" WC and deliver only 0.3–0.6" WC at the 12–18 CFM operating
point — below the 1.5–2.5" WC system minimum and with no margin for chaff
mesh loading (T8), distributor-plate variation, or the deeper bed in the 2.5"
chamber. This was a genuine blocker, not a paper one.

Three upgrade paths considered:
1. **Bypass-cooled vacuum motor + TRIAC** ($0–10 salvage, 20–80" WC headroom).
   Cost: AC complexity (zero-cross + TRIAC), brushed-motor EMI, larger
   envelope. ✓ Selected.
2. **24V high-pressure DC centrifugal** (Delta BFB1024-class + driver, $25–50,
   2–4" WC). Keeps everything LV-side. ✗ Conflicts with DR-001 cost target.
3. **Two 120 × 32 mm blowers in series** (~$15–20 incremental). Sums pressure
   but stalls in two places, no real headroom. ✗ Insufficient margin.

### Architecture changes

- **Air system:** unchanged (serial path).
- **Power domains:** Domain 2 changes from 12V DC to mains AC + TRIAC. PSU-002
  (12V/3A) deleted. Mains load increases by ~1–4 A (vacuum motor draw) — still
  within the 15A circuit budget alongside the heater (~12.5 A) only if the
  blower is run at modest duty during heating; verify total draw at TP-001.
- **Control:** ESP32 GPIO 23 reassigned from MOSFET PWM to TRIAC PWM input.
  GPIO 4 added for zero-cross interrupt. GPIO 34 added for ZMCT103C current
  sense (airflow interlock).
- **Safety:** `blower_is_running()` switches from PWM-duty inspection to
  CT RMS threshold. New FAULT_CT_OPEN if commanded-on with no current.
- **EMI:** Snap-on ferrites on all TC SPI cables (E13 cable shielding becomes
  necessary but not sufficient). Line filter on motor leads.
- **Grounding:** Motor frame bonded to mains earth (universal motors have
  nontrivial leakage current — bonding is safety-critical).

### Bypass-cooled is non-negotiable

Flow-through (single-stage) shop-vac motors cool the brushes with the working
airstream and shed brush carbon into it. Coffee application requires a
**bypass / two-stage** motor where a dedicated cooling impeller is isolated
from the working impeller. Inspect candidate motors and confirm the two
airpaths are separate before committing.

### BOM impact

| Action | BOM line | Notes |
|---|---|---|
| Modified | BLW-001 | Now: salvaged bypass-cooled vacuum motor, $0–10, status Thrift hunt |
| Deleted | PSU-002 | 12V/3A supply no longer needed |
| Deleted | Q1-001, R1-001, R2-001, D1-001 | MOSFET drive, gate resistors, flyback diode (12V blower drive parts) |
| Added | BLW-CTRL-001 | RobotDyn-style TRIAC dimmer module, 8A, ZC detect, ~$5–10 |
| Added | CT-001 | ZMCT103C 5A split-core current transformer, ~$3–8 |
| Added | FERR-001 | Snap-on ferrite chokes (set of 5–10), ~$5 |
| Added | FILT-001 | AC line filter / X+Y cap module on motor leads, ~$3–6 |
| Added | BOND-001 | Motor frame bonding lug + ring terminal, ~$1 |

Net cost impact: roughly neutral to slightly cheaper depending on the salvage
luck on the motor itself.

### Pending follow-on work — gated on parts in hand

**Hold all firmware and mechanical-fit work until the salvaged motor + the
DR-011 control kit (TRIAC dimmer, ZMCT103C, line filter, ferrites) are
physically on the bench.** The control-side details (PWM frequency / phase
math, CT burden value, ADC range, EMI envelope) depend on the actual hardware
and will be re-evaluated then. Re-open this entry as the trigger.

1. **Salvage hunt FIRST:** bypass-cooled motor from Habitat ReStore / curb /
   junk shop vac. Inspect dual-airpath separation before committing.
2. **Order DR-011 control kit:** validate ASINs for BLW-CTRL-001 (TRIAC
   dimmer), CT-001 (ZMCT103C), FILT-001 (line filter), FERR-001 (ferrites)
   per `bom/sourcing-notes.md` "Pending validation" table.
3. **Firmware (gated):** rewrite `blower.c` for phase-angle TRIAC drive off the
   zero-cross ISR; rewrite `blower_is_running()` against the CT ADC.
   Re-evaluate pin assignments, PWM strategy, and CT thresholding with the
   real boards in hand.
4. **SCAD model (gated):** the 150 mm × 200 mm best-estimate vacuum-motor
   envelope is a placeholder. Re-measure once a real motor is in hand.
5. **TP-001 update (gated):** P-Q characterization (formerly a critical gate)
   becomes "find the operating duty-cycle range." The motor will exceed
   system requirements at 100%; the question is where to operate it.

### What changed from previous decisions

- DR-003 (separate 12V brushless blower, MOSFET + PWM) — **superseded**.
  The "$15 over a thrift find buys us LV-only simplicity" trade was the wrong
  call once the P-Q gap became evident.
- DR-004 (three power domains: 120V AC heater, 12V DC blower, 3.3V DC
  controls) — **revised to two power domains**: 120V AC (heater + blower) and
  3.3V/5V DC (controls). The blower moves up to mains.
- E11 (LEDC PWM at 25 kHz for blower) — superseded; the new blower driver is
  phase-angle TRIAC, not high-frequency PWM. The 25 kHz LEDC infrastructure
  in firmware can be deleted.
- E9 (SS34 flyback diode upgrade) — moot; no flyback needed without the DC
  blower.

---

## 2026-04-13 — DR-010 formal design review response

### Summary

Formal design review (DR-010, 2026-04-12) produced 41 findings across 5 panels:
10 critical, 16 major, 15 minor. All findings accepted and incorporated except
two alternative-approach recommendations that were explicitly rejected.

### Rejected alternatives

1. **A1 REJECTED: Use intact heat gun body as heater can.** The heat gun housing
   will not be retained. The element will be extracted and mounted in a purpose-built
   heater can (2.5" SS exhaust pipe). Rationale: retaining the plastic housing
   limits thermal design flexibility, complicates mounting geometry, and the factory
   thermal cutout can be replaced by THFUSE-001 and THFUSE-002.

2. **A2 REJECTED: Use PID controller (Inkbird ITC-100VH) for v1 controls.** The
   ESP32-based control stack is retained for v1. Rationale: the ESP32 system
   provides data logging, multi-sensor monitoring, serial command interface, and
   future automation capability that a standalone PID controller cannot. The
   firmware safety bugs identified in DR-010 have been fixed directly.

### Accepted alternatives

3. **A3 ACCEPTED: Borosilicate glass tube as v1 chamber option.** Added to BOM as
   CHAM-001C. Will be tested alongside SS tubes in TP-001. Visual feedback on
   fluidization quality and roast development is valuable for the learning phase.

4. **A4 ACCEPTED: Roast on a popcorn popper first.** Added to BOM as POPPER-001.
   Calibrate operator senses (first-crack sound, roast progression, fluidization
   feel) before commissioning the custom roaster.

### Critical fixes implemented (firmware)

5. **F1: NAN bypass in over-temp check.** Added `isnan()` guard to every temperature
   comparison in `safety_check()`. NAN now triggers fault (fail-safe).

6. **E1/F2: Hardware watchdog.** Enabled ESP32 Task Watchdog Timer (TWDT) with
   5-second timeout. Fed every loop iteration. If firmware hangs, ESP32 resets —
   GPIO defaults to input/low on reset, de-energizing the SSR.

7. **E4/F3: Airflow interlock.** `safety_check()` now verifies `blower_is_running()`
   before allowing heater operation. Heater command with blower off triggers
   FAULT_AIRFLOW.

8. **F4: Startup race condition.** Safety system starts in new STARTUP state.
   Requires SAFETY_STARTUP_GOOD_READS (5) consecutive clean TC reads before
   transitioning to OK and allowing heater. Init order changed: safety_init()
   runs first.

9. **E3/F5: forced_off latch fix.** Added `heater_clear_forced_off()` function.
   `safety_reset()` clears the forced_off flag only after validating all TCs are
   reading valid and all temps are below SAFETY_RESET_TEMP_C (100°C).

10. **E12: safety_init() no longer calls heater_force_off().** This was prematurely
    latching the forced_off flag at boot. heater_init() already ensures GPIO is LOW.

### Major fixes implemented (firmware)

11. **E2/F8: safety_reset() now validates conditions.** Reset requires all TCs
    reading valid, all temps below 100°C. No longer unconditionally succeeds.

12. **F6: Stale sensor data rejection.** Sensors track last-update timestamp via
    `sensors_get_age_ms()`. Safety faults if data is older than 500ms.

13. **F7: Rate-of-change detection (dT/dt).** Safety tracks TC1 rate of change.
    Faults if rate exceeds 10°C/s (SAFETY_MAX_RATE_C_PER_S). New FAULT_RATE state.

14. **E13: Consecutive fault counter for SPI noise resilience.** Single bad SPI read
    no longer triggers TC fault. Requires SAFETY_CONSEC_FAULTS_TRIP (3) consecutive
    bad reads. Prevents false faults from EMI near 1500W burst-fire switching.

### Minor fixes implemented (firmware)

15. **E11: Proper LEDC PWM for blower.** Replaced `analogWrite()` (default ~1kHz)
    with explicit `ledcSetup()`/`ledcAttachPin()`/`ledcWrite()` at 25kHz. Above
    audible range, appropriate for brushless DC motor.

16. **F9: Command buffer overflow.** Already bounded by `cmd_pos < sizeof(cmd_buffer) - 1`
    check — characters beyond capacity silently discarded. Added clarifying comment.

### Electrical schematic changes

17. **E5: Fusing margin documented.** 12.5A continuous on 15A circuit is 83% (NEC
    requires ≤80% for continuous). Options documented: use 20A circuit, limit duty,
    or accept for bench testing.

18. **E6: Second thermal fuse (THFUSE-002).** Added 192–216°C thermal fuse in the
    heated airstream (lower rating, lower thermal lag than can-body fuse).

19. **E7: SSR drive buffer.** Added NPN transistor (2N2222) to buffer 3.3V GPIO to
    5V for reliable SSR triggering. Added Q2, R3 to schematic and BOM.

20. **E8: Double-pole disconnect.** SW-001 changed from SPST to DPST — switches
    both L and N to protect against reversed cord polarity.

21. **E9: Flyback diode upgrade.** D1 changed from 1N5819 (1A) to SS34 (3A) — blower
    draws 1-2A, 1A rating had insufficient margin.

22. **E10: RC snubber.** Added 47Ω + 0.01µF/400V X2-rated across SSR output.
    Suppresses inductive voltage spikes.

### Thermal/airflow documentation updates

23. **T1: Blower P-Q verification.** Documented as critical blocker in architecture.md.
    Must measure actual P-Q curve before committing to sizing.

24. **T2: Second plenum baffle.** Documented plan for second equalization stage if
    TP-001 shows single ramp insufficient. Added to block diagram air path.

25. **T3: L/D ratio slugging risk.** Documented in architecture.md — 2.5" chamber
    L/D ~1.0 exceeds Geldart D slugging threshold. 3.0" chamber (L/D ~0.57) is
    safer.

26. **T4: Insulation requirements.** 3.0" chamber cannot reach target temps without
    insulating heater can and plenum. Documented in architecture.md.

27. **T5: Umf operating margin.** Revised from 1.5× to 1.8–2.5× Umf. All airflow
    calculations updated for hot-air density. CFM requirements increased.

28. **T6-T8: Known thermal losses.** New section in architecture.md documenting
    moisture release (~30-40W), bean mass change (12-18%), and mesh clogging risk.

### Mechanical updates

29. **M1: Base stability.** Baseplate widened to 20"×12" in OpenSCAD model. Added
    BASE-001 to BOM with ballast and L-bracket requirements.

30. **M2: Plenum side-entry stub tube.** Added PLEN-005 to BOM — short SS tube stub
    through pan wall to prevent deformation under hose clamp.

31. **M3: Clamping ring load spreading.** Fender washers and backing strips specified
    in BOM notes for PLEN-002, PLEN-003, and FAST-001.

32. **M4: Chamber tube retention.** Added CHAM-RET-001 to BOM — set screws or spring
    clips through clamping ring. Never gravity alone.

33. **M5: Heater can build plan.** Added HTR-CAN-001 to BOM — build from 2.5" SS
    exhaust pipe, mount element via mica former tabs, insulate exterior.

34. **M6: Expansion chamber cone reducer.** Added EXH-004 to BOM — sheet metal cone
    from chamber OD to 4" expansion chamber, hose clamp at each end.

35. **M7: Pan burn-off.** Added note to PLEN-001 — burn off outdoors at full temp
    for 10 minutes before first use with beans.

36. **M8: Fiberglass gasket.** PLEN-004 changed from ceramic fiber to fiberglass
    stove rope/tape. Ceramic fiber sheds respirable particles.

37. **M9: TC compression fittings.** Added TC-FIT-001 to BOM — 1/8" Swagelok-style
    compression fittings for positive TC sealing and strain relief.

38. **M11: All-stainless hose clamps.** EXH-003 quantity increased, spec changed to
    all-stainless worm-drive (not zinc-plated) for temperature tolerance.

### BOM impact

BOM grew from 36 to 47 line items. New items added:
- THFUSE-002, Q2-001, R3-001, R-SNB-001, C-SNB-001 (electrical)
- CHAM-001C, PLEN-005, CHAM-RET-001, BASE-001, HTR-CAN-001, EXH-004, TC-FIT-001 (mechanical)
- POPPER-001 (reference/calibration)

Estimated cost impact: +$25-45, bringing target BOM to ~$75-125.

### Next actions

1. Source popcorn popper and do calibration roasts (A4)
2. Buy Warrior heat gun, tear down, measure element (unchanged)
3. Order 12V blower and **verify P-Q curve** (T1 — critical gate)
4. Order electronics including new buffer and snubber components
5. Build stable baseplate before any powered testing (M1)
6. Run TP-001 with both SS tubes and glass tube option

---

## 2026-04-11 — Plenum, baffle, and mechanical assembly decisions

### Decisions made

1. **DR-007: 1/6 size SS steam table pan as plenum body.** A standard 1/6 size,
   4" deep stainless steel steam table pan (~6.4" x 6.3" x 4") from restaurant
   supply, $4-8. 18/8 stainless, food-safe, rated for sustained heat. Provides
   generous volume for pressure equalization. Pan oriented right-side-up (open
   top faces up).

2. **DR-008: Bolted clamping ring assembly, no welding.** The distributor plate
   and roast chamber are held by a flat SS ring bolted across the pan rim with
   3-4 bolts through the flange. The ring's inner hole is sized to seat the
   distributor plate and the chamber tube. Swapping between 2.5" and 3.0"
   chambers means swapping the ring + plate pair. High-temp gasket material
   (fiberglass or ceramic fiber) between ring and pan rim for sealing.

   This resolves open question #6 (plenum adapter design): mechanical clamping
   ring, not welded adapter or stepped seat.

3. **DR-009: Deflector ramp baffle.** A single piece of SS sheet metal, bent to
   ~45°, mounted opposite the side-entry hole inside the plenum. Redirects the
   inlet jet downward toward the pan floor; air spreads across the full floor
   area then rises uniformly toward the distributor plate. Bolted or riveted
   in place.

   If TP-001 shows uneven fluidization, a horizontal perforated baffle can be
   added as a second equalization stage ~1" below the distributor plate. This
   is a future option, not built into v1 initially.

### Assembly concept (no welding required)

```
    ┌──── Roast Chamber Tube ────┐
    │    (sits inside ring)       │
    ├─────────────────────────────┤
    │    Distributor Plate        │  ← Perforated disc, rests on clamping ring
    ├─────────────────────────────┤
    │    Clamping Ring + Gasket   │  ← Bolted to pan rim (3-4 bolts)
    ╞═════════════════════════════╡  ← Pan rim/flange
    │         ╲                   │
    │          ╲ Deflector ramp   │  ← 45° bent SS, bolted opposite inlet
    │           ╲                 │
    ○ ← Side-entry from heater   │
    │                             │
    └─────────────────────────────┘
```

Tools required: drill, step bit or hole saw, tin snips, vise, wrench.
No welding, no brazing, no special fabrication.

### Open questions resolved

- Plenum adapter design (architecture.md Q6): **Resolved.** Bolted clamping
  ring with swappable ring + plate pairs for each chamber size.

---

## 2026-04-11 — Cooling, chaff collection, and air system design decisions

### Decisions made

1. **DR-005: Blower-only cooling cycle, no bypass damper for v1.** After SSR
   cutoff the heater can retains ~13-23 kJ of thermal energy. At 10-15 CFM
   forced convection, this dissipates in ~15-30 seconds — short enough that
   blower-only cooling (heater off, blower 100%) will bring 113g of beans from
   ~200°C to <50°C within 100-140 seconds. This is within the industry target
   of 90-150 seconds for small batches. A bypass damper or separate air paths
   are deferred until TP-002 cooldown data proves they're needed.

   **Mechanical hedge:** The blower-to-heater-can joint should use a hose clamp
   connection (not welded) so the heater can be physically disconnected for
   bypass cooling if thermal lag is worse than estimated.

   **Firmware addition:** A `COOL` command — sets heater to 0%, blower to 100%,
   logs cooldown curves, and notifies operator when TC2 < 50°C.

2. **DR-006: Expansion chamber + mesh screen for chaff collection.** 113g of
   green coffee produces ~0.5-0.9g of chaff, mostly at first crack. A removable
   expansion chamber at the exhaust captures chaff by velocity reduction:
   - ~4" OD × 5" tall stainless cylinder (step-up from roast chamber diameter
     drops air velocity to 2-4 ft/sec, chaff settles out)
   - 30×30 stainless mesh screen inside the top as a secondary capture plate
   - Removable for tap-and-empty cleaning between roasts
   - Negligible backpressure impact on fluidization

   This matches the proven approach used in Fresh Roast SR series and popcorn
   pumper conversions. A cyclone separator is overkill at 113g scale and adds
   significant backpressure.

### What changed from previous session

- Exhaust path is now explicitly a two-stage system: expansion chamber (chaff
  drops out) then mesh screen (secondary capture), both in a removable unit.
- Cooling is a defined operating mode, not just "turn the heater off."
- Heater can joint specified as hose clamp (not permanent) to preserve bypass
  option for future.

---

## 2026-04-11 — Heating and blower design decisions

### Decisions made

1. **DR-002: Warrior heat gun as heater element donor.** Harbor Freight Warrior
   1500W dual-temp heat gun (SKU 56434, ~$10) selected as the heating element
   source. Nichrome coil on mica former, 1000°F max, 11.25A at 120V. At $10
   this is essentially parts cost for the nichrome wire, mica former, and
   thermal cutout. Replaces the earlier "thrift store hair dryer" plan — the
   Warrior is cheap enough to buy new and has predictable, documented specs.

2. **DR-003: Separate 12V brushless blower, not scavenged AC motor.** The heat
   gun's built-in axial fan lacks the static pressure to fluidize a bean bed.
   A separate centrifugal blower is required. Selected a 12V brushless DC
   centrifugal blower (~$15-20, e.g. WDERAIR 120mm x 32mm) over a scavenged
   hair dryer universal motor. The 12V option costs ~$15 more than a thrift
   store find but keeps the blower on the low-voltage side, eliminating AC
   triac control complexity entirely.

3. **DR-004: Three explicit power domains.** The system has three power rails:
   - 120V AC mains → heating element via SSR
   - 12V DC → blower via MOSFET (from AC-DC switching PSU, 12V/3A sufficient)
   - 3.3V DC → ESP32 and sensors (USB or regulator)

   This cleanly separates mains-voltage control (SSR only) from low-voltage
   control (MOSFET PWM for blower, SPI for sensors, GPIO for everything).

### What changed from kickoff

- Hair dryer as combined heater+blower donor → split into dedicated heat gun
  element + dedicated 12V blower. Better for independent control, simpler
  electronics, small cost increase (~$25 vs ~$5).
- Blower driver changed from "TRIAC or DC, TBD" → definitively 12V DC via
  MOSFET + PWM from ESP32. No AC motor control needed on the blower side.
- 12V PSU moves from "only if DC blower" contingency to required BOM item.

### Open questions resolved

- Heater element sourcing (architecture.md Q2): **Resolved.** Warrior heat gun.
- Blower sourcing (architecture.md Q3): **Resolved.** 12V brushless centrifugal,
  MOSFET + PWM control.

---

## 2026-04-10 — Project kickoff and cost strategy

### Decisions made

1. **DR-001: Thrift-first cost strategy adopted.** Design around cheap available
   parts rather than specifying ideal parts and paying catalog prices. Target
   v1 BOM of $50-80. Full rationale in `design-reviews/DR-001-cost-strategy.md`.

2. **Dual chamber test approach.** Sourcing both 2.5" OD and 3.0" OD standard
   SS exhaust tube. The 2.5" gives significantly better thermal performance on
   120V (~1000W for ΔT=200°C vs ~1500W), but has a deeper bean bed (~6 cm vs
   ~4 cm) that may make fluidization harder. TP-001 will determine the winner.

3. **Hair dryer / heat gun as heater + blower donor.** A thrift store hair dryer
   ($2-5) provides both the ~1500W heater element and a matched blower motor.
   This collapses the two most expensive component selections into one cheap
   purchase. The heater can will be designed around the salvaged element geometry
   rather than the other way around.

4. **Design-to-available-parts sequence.** Because geometry depends on what parts
   we actually find, the build sequence is:
   - Source hair dryer → measure element → design heater can
   - Source plenum container → measure it → design baffles to fit
   - Source chamber tubes → confirm OD/ID → design plate and mounting
   - Order electronics (spec-driven, geometry-independent)
   - Final mechanical integration design after all parts are in hand

### Architecture established

- Repository structure created across 6 workstreams (system, mechanical,
  electrical, firmware, test, BOM/build)
- System block diagram with air, power, signal, and data paths
- Power/airflow budget calculations for both chamber sizes
- ESP32 firmware scaffold with safety, sensor, heater, blower, control,
  logging, and command modules
- 6 test plans covering airflow through first roast commissioning
- BOM with 25 line items and realistic cost estimates

### Open questions

- ~~Heater element: need to find and tear down a hair dryer to get real dimensions
  and measured wattage~~ **Resolved (DR-002):** Warrior heat gun, SKU 56434
- ~~Blower: is the hair dryer fan independently usable and speed-controllable?
  If not, a $10-15 12V brushless from Amazon is the fallback~~ **Resolved (DR-003):**
  12V brushless centrifugal, MOSFET + PWM control
- Plenum: need to find a suitable SS container and check thermal tolerance
- Plenum adapter: how to mount both 2.5" and 3.0" chamber tubes on the same
  plenum (adapter ring is the likely approach)
- Touchscreen UI: user has a 5x7" touchscreen LCD available. May add a
  Raspberry Pi as a UI tier above the ESP32 control layer. Interface type
  (HDMI, SPI, DSI) needs to be determined.

### Next actions

1. Buy Warrior heat gun from Harbor Freight (SKU 56434)
2. Tear down heat gun and document element resistance, dimensions, thermal cutout
3. Order 12V blower, MOSFET (IRLZ44N), flyback diode, 12V PSU (if not in junk drawer)
4. Order electronics (ESP32, MAX31855 x3, SSR, TCs, perforated SS sheet)
5. Source 2.5" and 3.0" SS exhaust pipe
6. Thrift store: SS containers for plenum
7. Once parts are in hand: mechanical integration design

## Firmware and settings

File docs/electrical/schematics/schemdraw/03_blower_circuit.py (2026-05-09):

"""Domain 2 - 120 V AC blower circuit (DR-011, supersedes DR-003).

Power path:
    L bus -> FILT-001 (X+Y line filter)
          -> CT-001 (ZMCT103C clamped on L lead, primary mains-isolated)
          -> BLW-CTRL-001 (RobotDyn-style TRIAC dimmer with on-board ZC detect)
          -> BLW-001 (aftermarket Lamb 116336-01-pattern bypass-cooled vacuum motor)
          -> N bus
    BOND-001 bonds the motor frame to chassis earth (universal motor leakage).

Logic side (3.3 V from ESP32):
    GPIO 23 (PWM out)  -> dimmer PWM in (gate trigger, phase-fired)
    GPIO 4  (ZC IRQ)   <- dimmer ZC out (one pulse per AC zero-cross)
    GPIO 34 (ADC)      <- CT-001 burden + bias network (RMS for airflow interlock)

Ferrite chokes (FERR-001) are clamped on the motor leads between TRIAC and
motor; not a schematic component but called out below.
"""
import schemdraw
import schemdraw.elements as elm

from common import WIRE_3V3, WIRE_L, WIRE_N, WIRE_PE, box, save, stem_from_argv0


def build() -> schemdraw.Drawing:
    d = schemdraw.Drawing(show=False)
    d.config(unit=2.5, fontsize=10)

    # ===================================================================
    # AC power path (top): L bus -> FILT -> CT -> TRIAC -> motor -> N bus
    # ===================================================================
    Y_AC = 0
    X_LBUS = 0
    X_NBUS = 30

    d += elm.Dot().at((X_LBUS, Y_AC)).label("L bus", "left")
    d += elm.Line().at((X_LBUS, Y_AC)).to((2, Y_AC)).color(WIRE_L)

    # FILT-001 - drawn as a labeled rectangle
    box(d, 2, Y_AC - 1, 5, Y_AC + 1)
    d += elm.Line().at((2, Y_AC)).to((5, Y_AC)).color(WIRE_L)
    d += elm.Label().at((3.5, Y_AC + 1.6)).label("FILT-001\nAC line filter\n(X + Y caps)", fontsize=9)

    # CT-001 (current transformer, drawn as inductor passing through the L line)
    d += elm.Line().at((5, Y_AC)).to((6.5, Y_AC)).color(WIRE_L)
    # Primary: just the L wire passing under/through; we show CT body as a box around it
    box(d, 6.5, Y_AC - 1, 9, Y_AC + 1)
    d += elm.Line().at((6.5, Y_AC)).to((9, Y_AC)).color(WIRE_L)
    d += elm.Label().at((7.75, Y_AC + 1.6)).label("CT-001\nZMCT103C 5A\n(split-core)", fontsize=9)

    # CT secondary tap to logic (drawn coming out the bottom)
    ct_sec = (7.75, Y_AC - 1)
    d += elm.Dot().at(ct_sec)
    d += elm.Line().at(ct_sec).down().length(2)

    # TRIAC dimmer module
    d += elm.Line().at((9, Y_AC)).to((11, Y_AC)).color(WIRE_L)
    box(d, 11, Y_AC - 2, 17, Y_AC + 2)
    d += elm.Line().at((11, Y_AC)).to((17, Y_AC)).color(WIRE_L)
    d += elm.Label().at((14, Y_AC + 1.4)).label(
        "BLW-CTRL-001\nTRIAC Dimmer  (RobotDyn-style 8 A)", fontsize=9)
    # Logic pins inside the dimmer box (PWM in, ZC out)
    pwm_pin = (12.5, Y_AC - 2)
    zc_pin = (15.5, Y_AC - 2)
    d += elm.Dot().at(pwm_pin).label("PWM in", "right", fontsize=8)
    d += elm.Dot().at(zc_pin).label("ZC out", "right", fontsize=8)

    # Ferrite choke + line out to motor
    d += elm.Line().at((17, Y_AC)).to((19, Y_AC)).color(WIRE_L)
    d += elm.Label().at((18, Y_AC + 0.7)).label("FERR-001\n(snap-on)", fontsize=8, color="#888888")

    # Motor (universal AC, drawn as an AC source / motor symbol)
    motor = d.add(elm.Motor().at((19, Y_AC)).right().label(
        "BLW-001\nUniversal AC\nbypass-cooled\nvacuum motor", "top"))
    d += elm.Line().at(motor.end).to((X_NBUS, Y_AC)).color(WIRE_N)
    d += elm.Dot().at((X_NBUS, Y_AC)).label("N bus", "right")

    # Earth bond (BOND-001) from motor frame to chassis ground stub
    d += elm.Line().at((motor.center.x, motor.center.y - 1.5)).down().length(2.5).color(WIRE_PE)
    d += elm.Ground().at((motor.center.x, motor.center.y - 4.0)).color(WIRE_PE)
    d += elm.Label().at((motor.center.x + 2.3, motor.center.y - 3.0)).label(
        "BOND-001\nframe -> chassis earth", fontsize=8, color=WIRE_PE)

    # ===================================================================
    # Logic side (bottom): ESP32 PWM/ZC/ADC connections
    # ===================================================================
    Y_ESP = -10
    X_ESP = 5

    # ESP32 stub
    box(d, X_ESP, Y_ESP - 2, X_ESP + 4, Y_ESP + 2)
    d += elm.Label().at((X_ESP + 2, Y_ESP)).label(
        "ESP32\nGPIO 23 (PWM)\nGPIO  4 (ZC IRQ)\nGPIO 34 (ADC)", fontsize=9)
    pin_pwm = (X_ESP + 4, Y_ESP + 1.2)
    pin_zc = (X_ESP + 4, Y_ESP + 0)
    pin_adc = (X_ESP + 4, Y_ESP - 1.2)
    d += elm.Dot().at(pin_pwm)
    d += elm.Dot().at(pin_zc)
    d += elm.Dot().at(pin_adc)

    # PWM out -> dimmer PWM in (purple = 3.3V logic)
    d += elm.Line().at(pin_pwm).to((11, Y_ESP + 1.2)).color(WIRE_3V3)
    d += elm.Line().at((11, Y_ESP + 1.2)).to((11, pwm_pin[1] - 0.001)).color(WIRE_3V3)
    d += elm.Line().at((11, Y_ESP + 1.2)).to((pwm_pin[0], Y_ESP + 1.2)).color(WIRE_3V3)
    d += elm.Line().at((pwm_pin[0], Y_ESP + 1.2)).to(pwm_pin).color(WIRE_3V3)

    # ZC out <- dimmer ZC out
    d += elm.Line().at(zc_pin).to((zc_pin[0], Y_ESP + 0)).color(WIRE_3V3)
    d += elm.Line().at((zc_pin[0], Y_ESP + 0)).to(pin_zc).color(WIRE_3V3)

    # CT secondary -> burden + bias network -> ADC
    # The CT secondary already drops down 2 units; carry it further to a small burden network
    # Burden: 62 ohm shunt (ZMCT103C typical)
    burden_top = (ct_sec[0], Y_AC - 3)
    burden_bot = (ct_sec[0], Y_AC - 5)
    d += elm.Resistor().at(burden_top).to(burden_bot).label("R-BURDEN\n62 ohm")
    # Bias divider: tap at midpoint up to ADC line
    bias_node = (ct_sec[0], Y_AC - 4)
    d += elm.Dot().at(bias_node)
    # Run a horizontal trace from bias_node down/right to the ADC pin
    d += elm.Line().at(burden_bot).down().length(0.8)
    d += elm.Ground().at((ct_sec[0], Y_AC - 5.8))
    # Bias net to ADC
    d += elm.Line().at(bias_node).to((pin_adc[0] + 4, bias_node[1])).color(WIRE_3V3)
    d += elm.Line().at((pin_adc[0] + 4, bias_node[1])).to((pin_adc[0] + 4, pin_adc[1])).color(WIRE_3V3)
    d += elm.Line().at((pin_adc[0] + 4, pin_adc[1])).to(pin_adc).color(WIRE_3V3)
    d += elm.Label().at((pin_adc[0] + 5.5, bias_node[1] + 0.6)).label(
        "(burden + bias\n to ADC mid-rail)", fontsize=8)

    # Title
    d += (elm.Label().at((15, Y_ESP - 5))
          .label("Domain 2 - Blower Circuit (120 V AC, DR-011)\n"
                 "Phase-angle TRIAC control with hardware ZC detect.\n"
                 "ZMCT103C airflow interlock: RMS sensed on GPIO 34 (replaces DR-003 PWM>0 check).\n"
                 "FERR-001 ferrite chokes on motor leads + every TC SPI cable. FILT-001 mandatory for SPI integrity.",
                 fontsize=9))

    return d


if __name__ == "__main__":
    save(build(), stem_from_argv0())

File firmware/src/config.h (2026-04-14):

#ifndef ROASTER_CONFIG_H
#define ROASTER_CONFIG_H

// =============================================================
// Pin Assignments
// IMPORTANT: Update these when electrical schematic is finalized
// =============================================================

// SPI bus (shared by all MAX31855 boards)
#define PIN_SPI_CLK   18
#define PIN_SPI_MISO  19
// MOSI not used by MAX31855 (read-only)

// MAX31855 chip select lines
#define PIN_TC1_CS    5     // TC1: Process air (post-heater, pre-plenum)
#define PIN_TC2_CS    16    // TC2: Bean bed (lower chamber)
#define PIN_TC3_CS    17    // TC3: Exhaust

// Heater SSR control
#define PIN_SSR       22    // Zero-cross SSR gate (active high)

// Blower control
#define PIN_BLOWER    23    // PWM output → MOSFET gate → 12V blower (DR-003)

// =============================================================
// Safety Thresholds
// =============================================================

#define SAFETY_MAX_PROCESS_TEMP_C   280.0f  // TC1 over-temp shutdown
#define SAFETY_MAX_EXHAUST_TEMP_C   250.0f  // TC3 over-temp shutdown
#define SAFETY_TC_FAULT_TIMEOUT_MS  2000    // Max time with bad TC reading before fault
#define SAFETY_RESET_TEMP_C         100.0f  // All TCs must be below this to allow reset (E2)
#define SAFETY_RESET_HYSTERESIS_C    20.0f  // Below max - hysteresis before reset allowed
#define SAFETY_STARTUP_GOOD_READS     5     // Consecutive good TC reads before heater enable (F4)
#define SAFETY_MAX_RATE_C_PER_S      10.0f  // Max allowed dT/dt before fault (F7)
#define SAFETY_SENSOR_STALE_MS      500     // Reject sensor data older than this (F6)
#define SAFETY_CONSEC_FAULTS_TRIP      3    // Consecutive bad SPI reads before TC fault (E13)

// =============================================================
// Control Parameters
// =============================================================

#define HEATER_PERIOD_MS        1000    // Burst-fire cycle period (1 second)
#define SENSOR_POLL_INTERVAL_MS 250     // 4 Hz sensor polling (report at 2 Hz)
#define LOG_INTERVAL_MS         500     // 2 Hz data output to serial
#define SERIAL_BAUD             115200
#define BLOWER_PWM_FREQ         25000   // 25 kHz PWM frequency (E11)
#define BLOWER_PWM_CHANNEL      0       // LEDC channel for blower
#define BLOWER_PWM_RESOLUTION   8       // 8-bit resolution (0-255)
#define WDT_TIMEOUT_S           5       // Hardware watchdog timeout in seconds (E1/F2)

// =============================================================
// Cooling Cycle (DR-005)
// =============================================================

#define COOL_TARGET_TEMP_C      50.0f   // TC2 threshold to signal "beans cool"
#define COOL_BLOWER_PERCENT     100     // Blower duty during cooling

// =============================================================
// Thermocouple Count
// =============================================================

#define TC_COUNT 3

#endif // ROASTER_CONFIG_H

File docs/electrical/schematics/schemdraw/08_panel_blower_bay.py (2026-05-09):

"""Panel-wiring pictorial: BLOWER BAY zone (DR-011).

Mains side:
    L bus pigtail -> FILT-001 L-in
                  -> FILT-001 L-out -> CT-001 P1 -> CT-001 P2 -> BLW-CTRL-001 AC-In L
                  -> BLW-CTRL-001 AC-Out L -> [FERR-001] -> BLW-001 L
    N bus pigtail -> FILT-001 N-in -> FILT-001 N-out -> BLW-CTRL-001 AC-In N
                  -> BLW-CTRL-001 AC-Out N -> [FERR-001] -> BLW-001 N

Earth:
    PE pigtail -> bay PE bus
    FILT-001 PE tab -> PE bus
    BLW-001 motor frame -> PE bus  (BOND-001 - mandatory; universal motor leakage)

Logic side:
    CT-001 secondary -> burden + bias network -> C-CT-A cable to control bay GPIO 34
    BLW-CTRL-001 4-pin header (VCC, GND, ZC, PWM) -> control bay
"""
import schemdraw
import schemdraw.elements as elm

from common import (C_3V3, C_5V, C_GND, C_L, C_N, C_PE, C_SIG,
                    cable_schedule, module, save, stem_from_argv0, term, wire,
                    zone)


def build() -> schemdraw.Drawing:
    d = schemdraw.Drawing(show=False)
    d.config(unit=2.0, fontsize=9)

    Z_X0, Z_Y0, Z_X1, Z_Y1 = 0, 0, 32, 18
    zone(d, Z_X0, Z_Y0, Z_X1, Z_Y1, "BLOWER BAY  (mains side, DR-011)")

    Y_AC_L = 14.0  # AC L rail (top)
    Y_AC_N = 12.5  # AC N rail (just below L)

    # ---- Incoming pigtails from MAINS ENTRY (top edge) ----
    in_l = (3, 17.4)
    in_n = (5, 17.4)
    in_pe = (7, 17.4)
    d.add(elm.Dot(open=True).at(in_l).label("L  (C-MN-4)", "top", fontsize=7))
    d.add(elm.Dot(open=True).at(in_n).label("N  (C-MN-5)", "top", fontsize=7))
    d.add(elm.Dot(open=True).at(in_pe).label("PE  (C-PE-2)", "top", fontsize=7))

    wire(d, in_l, (3, Y_AC_L), C_L, "BLK 14 AWG", label_at=(3.5, 16.0))
    wire(d, in_n, (5, Y_AC_N), C_N, "WHT 14 AWG", label_at=(5.5, 15.5))
    wire(d, in_pe, (7, 1.5), C_PE, "GRN 14 AWG", label_at=(7.5, 9.5))

    # ---- FILT-001 (line filter) ----
    filt_x0, filt_y0, filt_x1, filt_y1 = 4, 11.5, 7.5, 14.5
    module(d, filt_x0, filt_y0, filt_x1, filt_y1, "FILT-001  EMI line filter")
    filt_l_in = term(d, (filt_x0, Y_AC_L), "L-in", "left")
    filt_n_in = term(d, (filt_x0, Y_AC_N), "N-in", "left")
    filt_l_out = term(d, (filt_x1, Y_AC_L), "L-out", "right")
    filt_n_out = term(d, (filt_x1, Y_AC_N), "N-out", "right")
    filt_pe = term(d, ((filt_x0 + filt_x1) / 2, filt_y0), "PE", "bottom")

    # ---- CT-001 (split-core current transformer, primary clamps on L wire) ----
    ct_x0, ct_x1 = 9, 11
    module(d, ct_x0, Y_AC_L - 0.7, ct_x1, Y_AC_L + 0.7, "CT-001  ZMCT103C")
    ct_p1 = term(d, (ct_x0, Y_AC_L), "P1", "left")
    ct_p2 = term(d, (ct_x1, Y_AC_L), "P2", "right")
    ct_s1 = term(d, ((ct_x0 + ct_x1) / 2 - 0.3, Y_AC_L - 0.7), "S1", "bottom")
    ct_s2 = term(d, ((ct_x0 + ct_x1) / 2 + 0.3, Y_AC_L - 0.7), "S2", "bottom")

    # ---- BLW-CTRL-001 (TRIAC dimmer) ----
    bc_x0, bc_y0, bc_x1, bc_y1 = 13, 8.5, 19, 15.0
    module(d, bc_x0, bc_y0, bc_x1, bc_y1, "BLW-CTRL-001  TRIAC dimmer")
    bc_l_in = term(d, (bc_x0, Y_AC_L), "AC-In L", "left")
    bc_n_in = term(d, (bc_x0, Y_AC_N), "AC-In N", "left")
    bc_l_out = term(d, (bc_x1, Y_AC_L), "AC-Out L", "right")
    bc_n_out = term(d, (bc_x1, Y_AC_N), "AC-Out N", "right")
    bc_vcc = term(d, (bc_x0 + 0.7, bc_y0), "VCC", "bottom")
    bc_gnd = term(d, (bc_x0 + 2.0, bc_y0), "GND", "bottom")
    bc_zc = term(d, (bc_x0 + 3.5, bc_y0), "ZC", "bottom")
    bc_pwm = term(d, (bc_x0 + 5.0, bc_y0), "PWM", "bottom")
    d.add(elm.Label().at(((bc_x0 + bc_x1) / 2, bc_y0 + 1.0)).label(
        "phase-fired TRIAC w/\non-board ZC detect", fontsize=7))

    # FERR-001 ferrite call-out (between dimmer and motor)
    d.add(elm.Label().at((20.5, Y_AC_L + 0.8)).label("FERR-001\n(snap-on)", fontsize=7, color="#888888"))

    # ---- BLW-001 (universal AC vacuum motor) ----
    blw_x0, blw_y0, blw_x1, blw_y1 = 22, 10.5, 28, 14.5
    module(d, blw_x0, blw_y0, blw_x1, blw_y1, "BLW-001  vacuum motor")
    blw_l = term(d, (blw_x0, Y_AC_L), "L", "left")
    blw_n = term(d, (blw_x0, Y_AC_N), "N", "left")
    blw_pe = term(d, ((blw_x0 + blw_x1) / 2, blw_y0), "frame", "bottom")
    d.add(elm.Label().at(((blw_x0 + blw_x1) / 2, blw_y0 + 1.0)).label(
        "universal AC,\nbypass-cooled,\n~1-4 A draw", fontsize=7))

    # ---- L rail wires ----
    wire(d, (3, Y_AC_L), filt_l_in, C_L, "BLK 14 AWG")
    wire(d, filt_l_out, ct_p1, C_L, "BLK 14 AWG")
    wire(d, ct_p2, bc_l_in, C_L, "BLK 14 AWG")
    wire(d, bc_l_out, blw_l, C_L, "BLK 14 AWG")

    # ---- N rail wires ----
    wire(d, (5, Y_AC_N), filt_n_in, C_N, "WHT 14 AWG")
    wire(d, filt_n_out, bc_n_in, C_N, "WHT 14 AWG")
    wire(d, bc_n_out, blw_n, C_N, "WHT 14 AWG")

    # ---- Burden + bias network for CT-001 secondary ----
    # Drawn just below CT-001 as two resistors (burden + bias divider). The output
    # is a single-ended AC waveform riding on +1.65 V (mid-rail), routed to GPIO 34.
    bn_x0, bn_y0, bn_x1, bn_y1 = 8.5, 6.5, 11.5, 9.0
    module(d, bn_x0, bn_y0, bn_x1, bn_y1, "BN-001  burden + bias")
    bn_in_a = term(d, (bn_x0, 8.5), "S1", "left")
    bn_in_b = term(d, (bn_x0, 7.5), "S2", "left")
    bn_out_sig = term(d, (bn_x1, 8.5), "out (AC)", "right")
    bn_out_gnd = term(d, (bn_x1, 7.0), "GND", "right")
    d.add(elm.Label().at(((bn_x0 + bn_x1) / 2, bn_y0 - 0.4)).label(
        "62 ohm burden across S1-S2;\nresistor divider biases\noutput to mid-rail (1.65 V)",
        fontsize=7))

    wire(d, ct_s1, bn_in_a, C_SIG, route="v-then-h")
    wire(d, ct_s2, bn_in_b, C_SIG, route="v-then-h")
    d.add(elm.Label().at((ct_s1[0] - 0.3, 9.5)).label(
        "twisted pair\nshielded", "left", fontsize=6, color=C_SIG))

    # ---- PE / chassis-earth bus along bottom ----
    d.add(elm.Line().at((1, 1.5)).to((30, 1.5)).color(C_PE))
    d.add(elm.Label().at((15, 0.9)).label(
        "Chassis earth bus  (GRN 14 AWG)  -  FILT PE, motor frame (BOND-001), bay panel",
        fontsize=8, color=C_PE))
    # Drops onto the bus
    wire(d, filt_pe, (filt_pe[0], 2.4), C_PE)
    d.add(elm.Dot().at((filt_pe[0], 2.4)))
    d.add(elm.Label().at((filt_pe[0], 2.7)).label("FILT-001 PE", fontsize=7, color=C_PE))
    wire(d, blw_pe, ((blw_x0 + blw_x1) / 2, 2.4), C_PE, "BOND-001  GRN 14 AWG", label_at=(25.5, 5.0))
    d.add(elm.Dot().at(((blw_x0 + blw_x1) / 2, 2.4)))
    d.add(elm.Label().at(((blw_x0 + blw_x1) / 2, 2.7)).label("BLW-001 frame", fontsize=7, color=C_PE))
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

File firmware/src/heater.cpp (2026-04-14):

#include "heater.h"
#include "config.h"
#include "safety.h"

static uint8_t duty_percent = 0;
static bool forced_off = false;
static bool output_state = false;
static unsigned long period_start_ms = 0;

void heater_init() {
    pinMode(PIN_SSR, OUTPUT);
    digitalWrite(PIN_SSR, LOW);
    duty_percent = 0;
    forced_off = false;
    output_state = false;
}

void heater_set_duty(uint8_t percent) {
    if (percent > 100) percent = 100;
    duty_percent = percent;
}

uint8_t heater_get_duty() {
    return duty_percent;
}

void heater_update() {
    // Safety override — always check first
    if (forced_off || !safety_heater_allowed()) {
        digitalWrite(PIN_SSR, LOW);
        output_state = false;
        return;
    }

    unsigned long now = millis();
    unsigned long elapsed = now - period_start_ms;

    // Start new period
    if (elapsed >= HEATER_PERIOD_MS) {
        period_start_ms = now;
        elapsed = 0;
    }

    // Burst-fire: ON for (duty_percent / 100) of the period
    unsigned long on_time = (unsigned long)duty_percent * HEATER_PERIOD_MS / 100;

    if (elapsed < on_time && duty_percent > 0) {
        digitalWrite(PIN_SSR, HIGH);
        output_state = true;
    } else {
        digitalWrite(PIN_SSR, LOW);
        output_state = false;
    }
}

void heater_force_off() {
    forced_off = true;
    duty_percent = 0;
    digitalWrite(PIN_SSR, LOW);
    output_state = false;
}

void heater_clear_forced_off() {
    // F5/E3: Only called by safety_reset() after validating all conditions are safe.
    // Does NOT re-enable the heater — just clears the latch so future commands work.
    forced_off = false;
}

bool heater_is_on() {
    return output_state;
}

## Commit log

2026-04-11 heater and blower decision
    [bom-master.csv]
2026-04-11 cooling strategy
    [bom-master.csv]
2026-04-11 plenum strategy
    [bom-master.csv]
2026-04-11 electrical and mechanical diagrams
    [bom-master.csv, roaster-assembly.scad]
2026-04-14 revisions based on design review
    [bom-master.csv, roaster-assembly.scad]
2026-04-29 updated sourcing links
    [bom-master.csv]
2026-04-30 upsized blower approach
    [bom-master.csv, roaster-assembly.scad]
2026-04-30 baseplate layout doc + validated DR-011 sourcing
    - New docs/mechanical/baseplate-layout.md: four-zone top-down layout
    (blower/heater/chimney/electronics), Zone-D component placement,
    three-lane wire routing rules, grounding bus topology. Notes the
    blower envelope vs current 20" baseplate constraint and proposes
    vertical-axis motor mounting as the working assumption. SCAD model
    intentionally untouched per DR-011 gating.
    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
    [bom-master.csv]
2026-05-03 DR-012 stovepipe plenum + DR-008 ring geometry fix + sourcing updates
    - DR-012: 8in x 6in black stovepipe section, both ends pipe-capped,
    supersedes the 1/6 SS steam table pan from DR-007. Round body matches
    the round chamber, height optimized for jet dissipation + T2 headroom,
    no zinc outgassing concerns vs galvanized HVAC duct.
    - DR-008 ring geometry corrected (Option A): ring ID was specced equal
    to plate dia, leaving the plate with no rest surface. Now ring ID <
    chamber ID with plate dropped inside the chamber bottom and chamber
    rim resting on the same ring face. Fastening changed to tapped ring
    with M4 from above so DR-008 swap doesn't require breaking the new
    bottom-cap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
    [bom-master.csv]
2026-05-04 DR-013 pre-build review: instrumentation, plate plan, dual top-caps, 20A circuit
    Pre-build design review across five decisions (D1-D5) before any irreversible
    plenum or distributor-plate fab. No architectural commitments moved; only
    parameter-level decisions inside existing commitments.
    - D1: run FengYoo 22%-open plates as-is; MESH-001 (40-mesh SS cloth) staged
    as on-hand Plan B; DIY-drilled custom plate held as Plan C
    - D2: procedural rule is the actual plate-float mitigation. The "heavier
    plate" decision is withdrawn — re-derivation shows no reasonable sheet
    gauge clears the corrected 72 gf lift threshold (DR-008 entry overstated
    the force by ~7x; corrected inline)
    - D3: build b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
    [bom-master.csv]
2026-05-07 updated for actual parts
    [bom-master.csv, roaster-assembly.scad]
2026-05-08 improved schematics
2026-05-09 BLW-001 airflow architecture confirmation + motor photos
    Confirmed the aftermarket vacuum motor (Amazon B0F89ZQ23G) is a true
    peripheral-bypass design with a ø1.50in axial working-air intake on the
    disc bottom face and peripheral louvered discharge — established from
    the seller's own listing claim, the genuine Ametek Lamb 116336-01
    Product Bulletin (March 1998) the part replicates, and visual
    verification of the unit in hand. BOM updated to reflect aftermarket
    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
    [bom-master.csv]
2026-05-09 update docs to reflect aftermarket BLW-001 sourcing
    Replace stale "salvaged vacuum motor" framing across the design docs
    now that BLW-001 is confirmed as an aftermarket Lamb 116336-01-pattern
    unit (Amazon B0F89ZQ23G, ~$60-90), not a curb-find shop vac. Also
    correct the SCAD blower outlet diameter from 50mm to 38mm (1.5in)
    to match the BLW-HOUS-001 OEM fan-shell pipe outlet, and regenerate
    the schemdraw SVGs to drop "Salvaged" from the panel-wiring labels.
    [roaster-assembly.scad]
2026-05-09 DR-015: BLW-HOUS-001 outlet is axial, add elbow + accessories
    The Ametek-Lamb 45899-14 fan shell's 1.5in pipe outlet exits the dome
    face axially (parallel to the motor shaft, off-center), not radially as
    the DR-014 BOM line described. Confirmed via direct inspection of the
    Ace Vacuums product photo. With BLW-001 mounted shaft-vertical, that
    puts the discharge straight up, so a 1.5in silicone 90deg elbow
    (BLW-ELBOW-001) is added to redirect horizontal-forward to the heater
    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
    [bom-master.csv, roaster-assembly.scad]
2026-05-09 swap BLW-HOUS-001 primary source to Amazon
    Single-vendor air-train order: house, gasket, elbow, and reducer all
    on Amazon. The Vacuum Factory remains as a cheaper non-Amazon
    alternative (~$12 less for the housing) if Amazon stock or pricing
    shifts.
    [bom-master.csv]
2026-05-12 DR-016 + DR-017: Heater Enable panel + Pi 5 / Zone E host architecture
    DR-016 (Operator UI architecture):
    - Hardware Heater Enable switch (SW-002) in series with ESP32->SSR control
    line; ESP also reads switch state on GPIO 35 to refuse heater duty when
    disabled. Establishes four-level heater authority hierarchy (firmware ->
    hw switch -> thermal fuses -> DPST).
    - Artisan-as-UI commitment: no panel pots, no AUTO/MANUAL toggle, no
    on-device screen on v1. USB serial-watchdog handles host-drop failure.
    - Minimal safety panel = SW-001 DPST + SW-002 Heater Enable + LED-001
    POWER + LED-002 FAULT.
    DR-017 (Host platform):
    - Raspberry Pi 5 8GB + on-hand 5x7" HDMI touch display as integrated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
    [bom-master.csv, roaster-assembly.scad]
